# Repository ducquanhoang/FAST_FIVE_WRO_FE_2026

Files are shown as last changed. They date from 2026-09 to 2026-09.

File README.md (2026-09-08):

# FAST-FIVE_WRO_FE_2026
## WRO Future Engineers - Robotics Project Documentation
## Hello! Out team is called "Fast Five"

### Our team
| Photo | Member Name | Role & Experience |
| ----- | --- | --- |
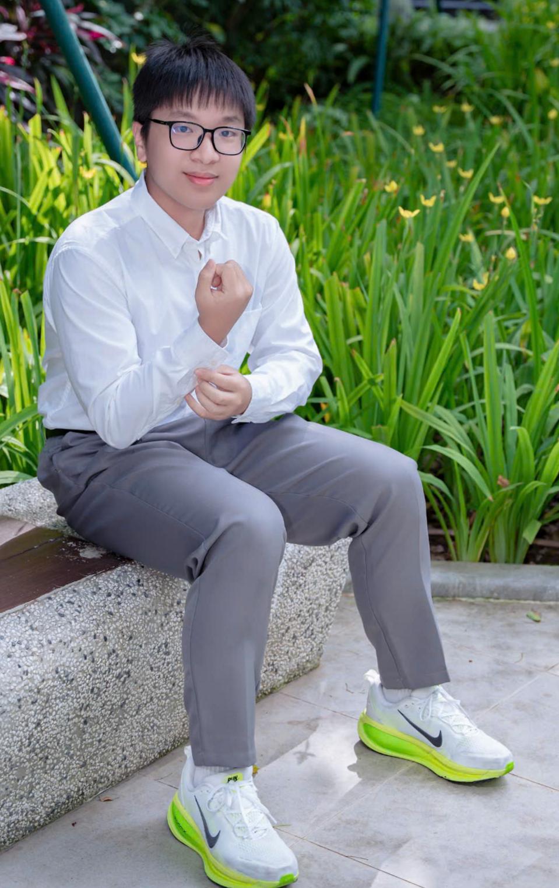
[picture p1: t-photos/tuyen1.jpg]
|| Nguyễn Tự Tuyển | Role: Responsible for documenting the team's development process and photography. Experience: First time competing in an official WRO event |
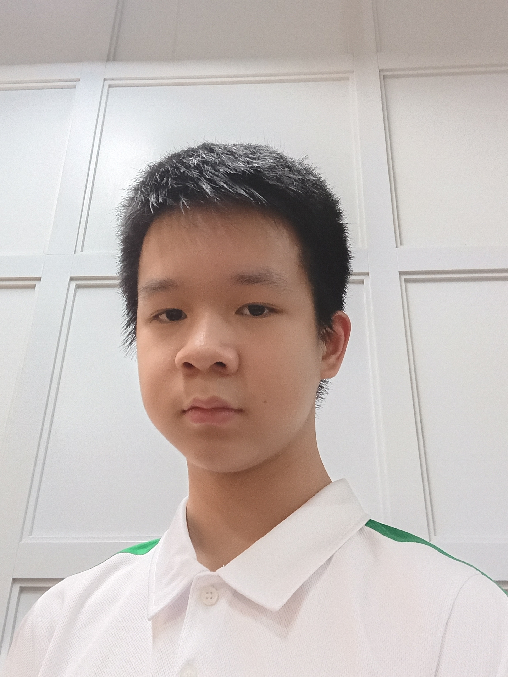
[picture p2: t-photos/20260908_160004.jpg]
|| Hoàng Đức Quân  | Role: Documenting part of the team's development, designing, building and programming the robot. Experience: Previously competed in WRO B2 category 2026 year at hanoi city round, south korean open round, and vietnam national round |

## Table of Contents
- [1. Overview](#1-overview)
  - [1.1 About the Project](#11-about-the-project)
  - [1.2 Robot Images](#12-robot-images)
  - [1.3 Repository Content](#13-repository-content)
- [2. Mobility Management](#2-mobility-management)
  - [2.1 Drive System](#21-drive-system)
  - [2.2 Steering](#22-steering)
  - [2.3 Chassis Design](#23-chassis-design)
- [3. Power and Sense Management](#3-power-and-sense-management)
  - [3.1 Power Source](#31-power-source)
  - [3.2 Sensors and Camera](#32-sensors-and-camera)
  - [3.3 Processing Units](#33-processing-units)
  - [3.4 Port / Wiring Map](#34-port--wiring-map)
  - [3.5 Power Consumption](#35-power-consumption)
- [4. Obstacle Management](#4-obstacle-management)
  - [4.1 Open Challenge](#41-open-challenge)
  - [4.2 Obstacle Challenge](#42-obstacle-challenge)
  - [4.3 Parallel Parking](#43-parallel-parking)
- [5. Source Code](#5-source-code)
  - [5.1 Code Overview](#51-code-overview)
  - [5.2 Code Structure](#52-code-structure)
  - [5.3 Upload / Run Instructions](#53-upload--run-instructions)
- [6. List of Components](#6-list-of-components)
- [7. Building Instructions](#7-building-instructions)
- [8. Future Improvements](#8-future-improvements)
  - [8.1 Software](#81-software-and-reliability)
  - [8.2 Hardware](#82-hardware)

---

## 1. Overview

### 1.1 About the Project

This project of ours is a self‑driving car for the WRO Future Engineers category. The car's a vehicle that can finish the Open Challenge, which asks for three laps on a random track without touching a wall. The car can also complete the Obstacle Challenge, which requires three laps while reading green traffic signs and then doing parallel parking. 

This is the year our team has competed in this category, so much of the project involved learning engineering and programming skills from scratch.

Our robot is built on a custom LEGO Technic + 3D-printed (PLA) chassis, in a rear-wheel differential-drive, Ackermann front-steer configuration, controlled by a LEGO® Education SPIKE™ Prime Hub and a Matrix Robotics M-Vision Cam for onboard image processing. Design priorities, in order, were: a low center of gravity for stability, a lightweight structure to reduce motor strain, and a minimal footprint for maneuverability.

### 1.2 Robot Images

<table>
  <tr>
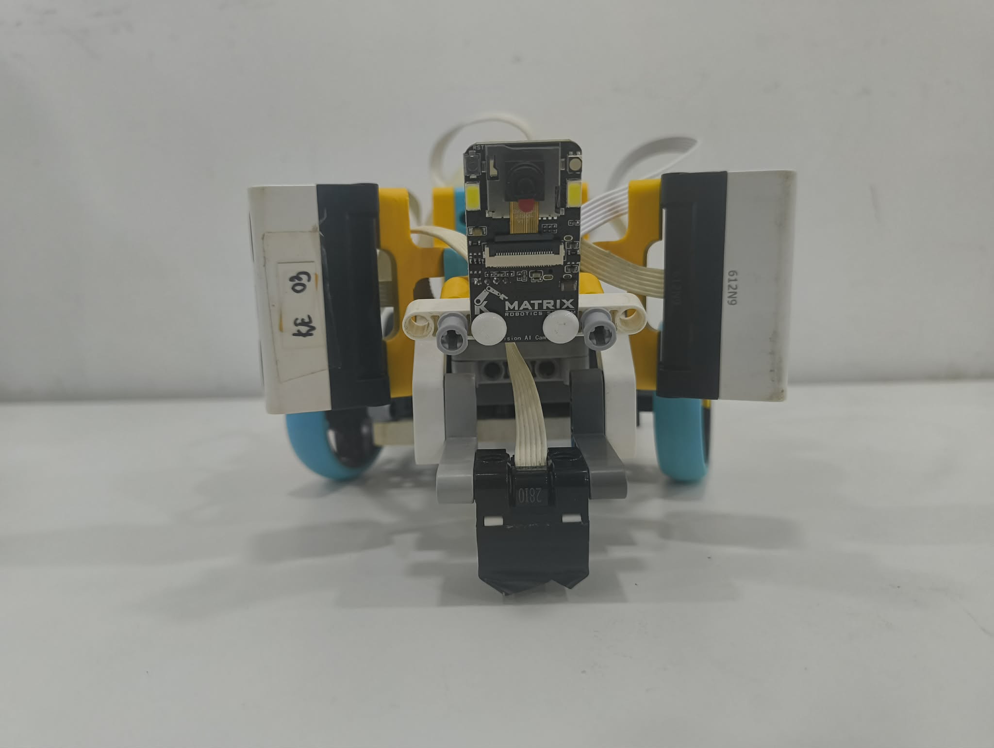
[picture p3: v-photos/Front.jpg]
    <td align="center"><b>Front View</b><br></td>
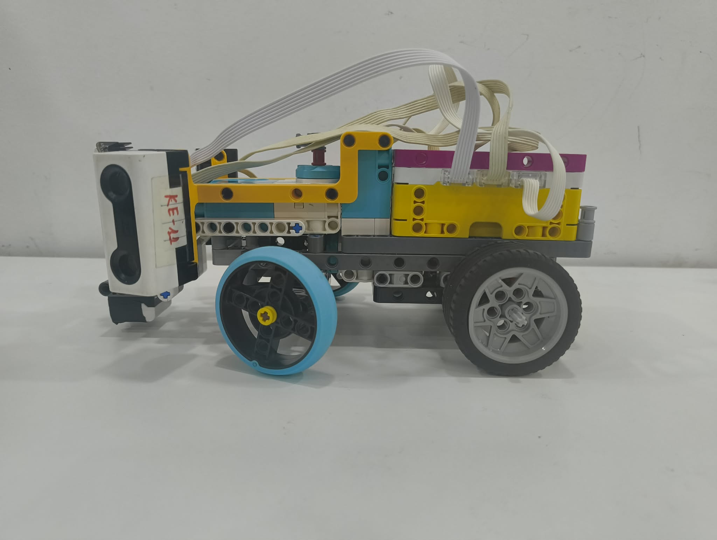
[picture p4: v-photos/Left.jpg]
    <td align="center"><b>Left View</b><br></td>
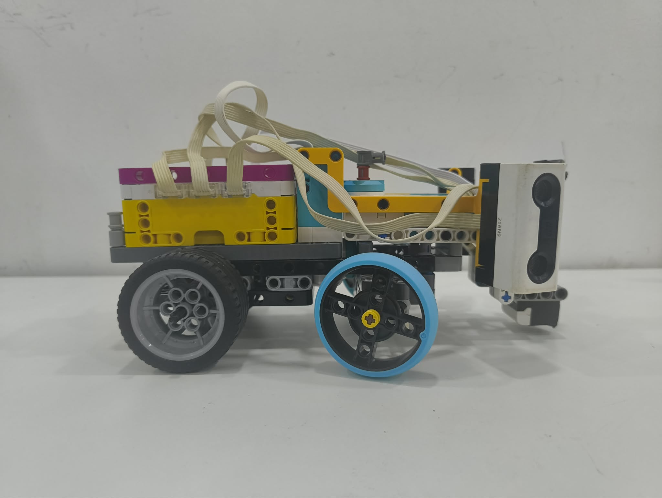
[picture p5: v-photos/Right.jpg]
    <td align="center"><b>Right View</b><br></td>
  </tr>
  <tr>
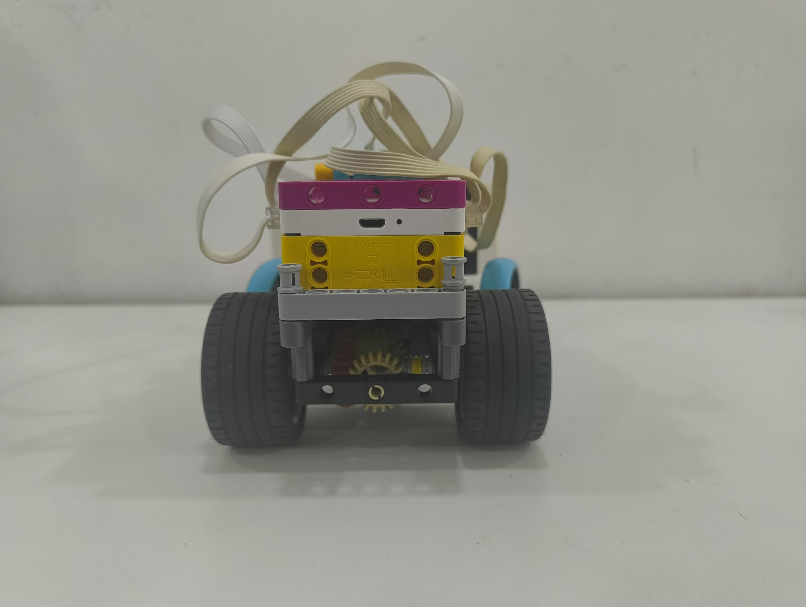
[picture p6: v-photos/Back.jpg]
    <td align="center"><b>Back View</b><br></td>
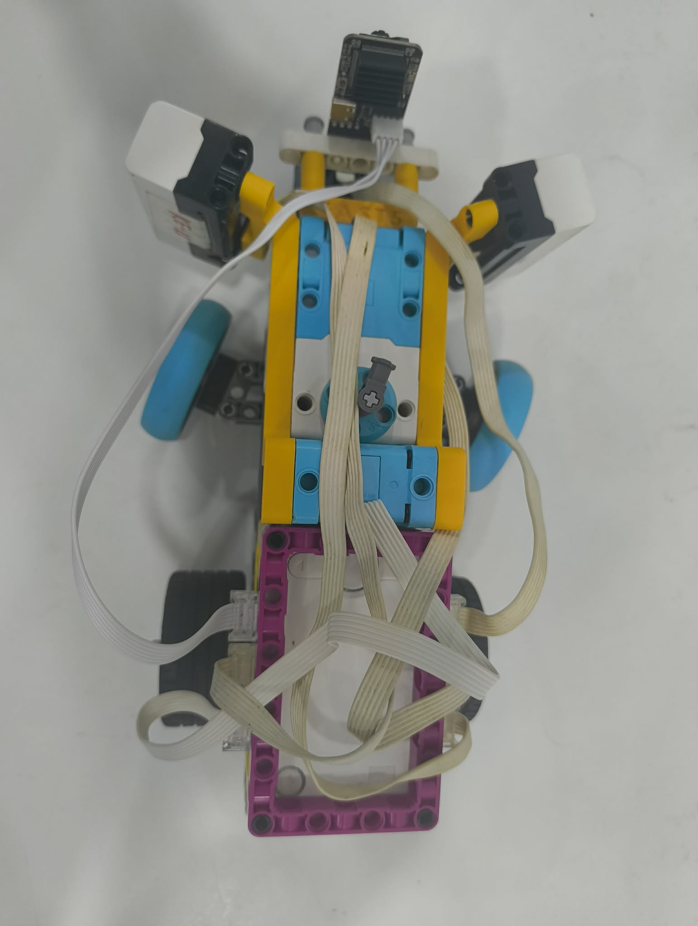
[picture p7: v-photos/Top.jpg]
    <td align="center"><b>Top View</b><br></td>
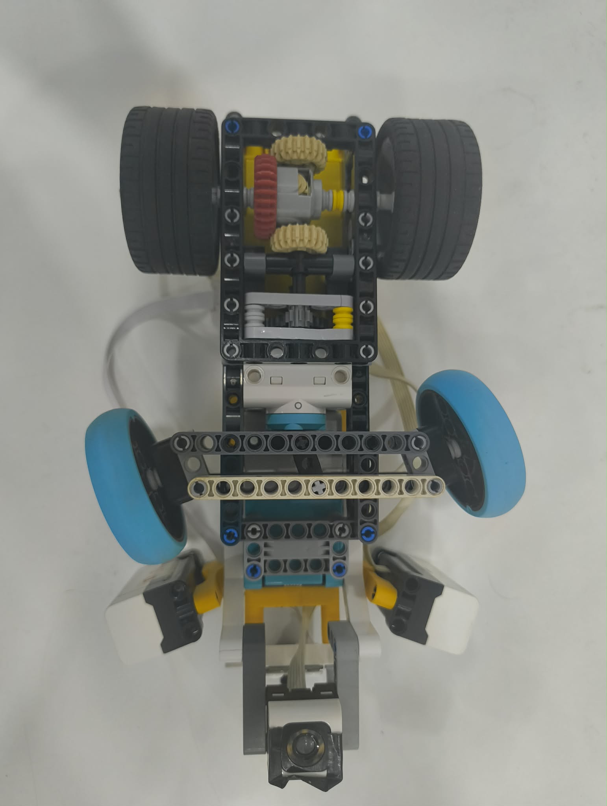
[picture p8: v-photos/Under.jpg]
    <td align="center"><b>Bottom View</b><br></td>
  </tr>
</table>

### 1.3 Repository Content
| Folder | Content |
| --- | --- |
| [t-photos](t-photos) | photo of team members |
| [v-photos](v-photos) | photos of the vehicle, including view from all 6 directions |
| [source code](scr) | python source code for the vehicle's camera and controller |
| [schemes](schemes) | diagrams used |
| [Model](Model) | Photo of component models and 3D model for ultra_adapter and cam_holder |

---

## 2. Mobility management
Design objective: Our chassis is built around 3 goals: stability (keep a low, balanced center of gravity so the robot doesn’t tip or wobble to the side during hard turns or sudden acceleration, and a steady drive base for the camera), efficiency (a lightweight structure so the drive motor isn't fighting excess mass), and maneuverability (a compact footprint that can navigate tight corners and obstacles without sacrificing control).
Motor: LEGO® Technic™ Large Angular Motor (drives the rear differential)
### 2.1 Drive System
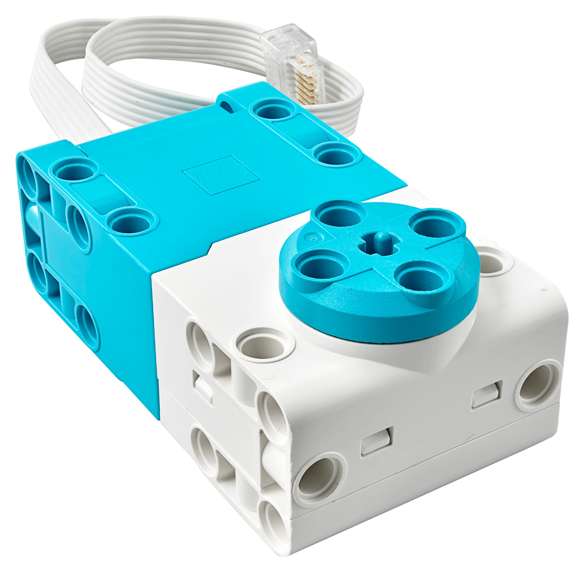
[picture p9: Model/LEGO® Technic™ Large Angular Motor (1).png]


Specifications
* Connector: LEGO® Power Functions 2.0 (LPF2)
* Voltage range: 5–9V (SPIKE Hub nominal: 7.2V)
* No-load speed: ~175 RPM (team measurement, vs ~135 RPM for the stock SPIKE-branded Large Angular Motor)
* Feedback: integrated rotation/position sensor|

Reason for Selection

Higher RPM than the stock SPIKE motor, for faster lap times on the flat competition arena.
Smaller footprint with more mounting-hole positions on the case, giving flexibility in where it sits on the chassis.
Built-in rotation sensor gives closed-loop feedback for encoder-based distance/angle control.

### 2.2 Steering
Motor: LEGO® Technic™ Large Angular Motor + 1:1 gearbox



Specifications
* Connector: LPF2
* Voltage range: 5–9V
* Stall torque: ~40 N·cm with the 1:1 gearbox (team measurement, vs ~25 N·cm for the stock SPIKE Angular Motor)
* Feedback: integrated rotation/position sensor, used for heading/angle-based turns (`MotorB_Angle`)
* Reason for Selection :Highest available stall torque among LEGO Powered Up motors, needed to move the Ackermann linkage under load.
Position feedback lets steering angle be driven and held precisely rather than open-loop.

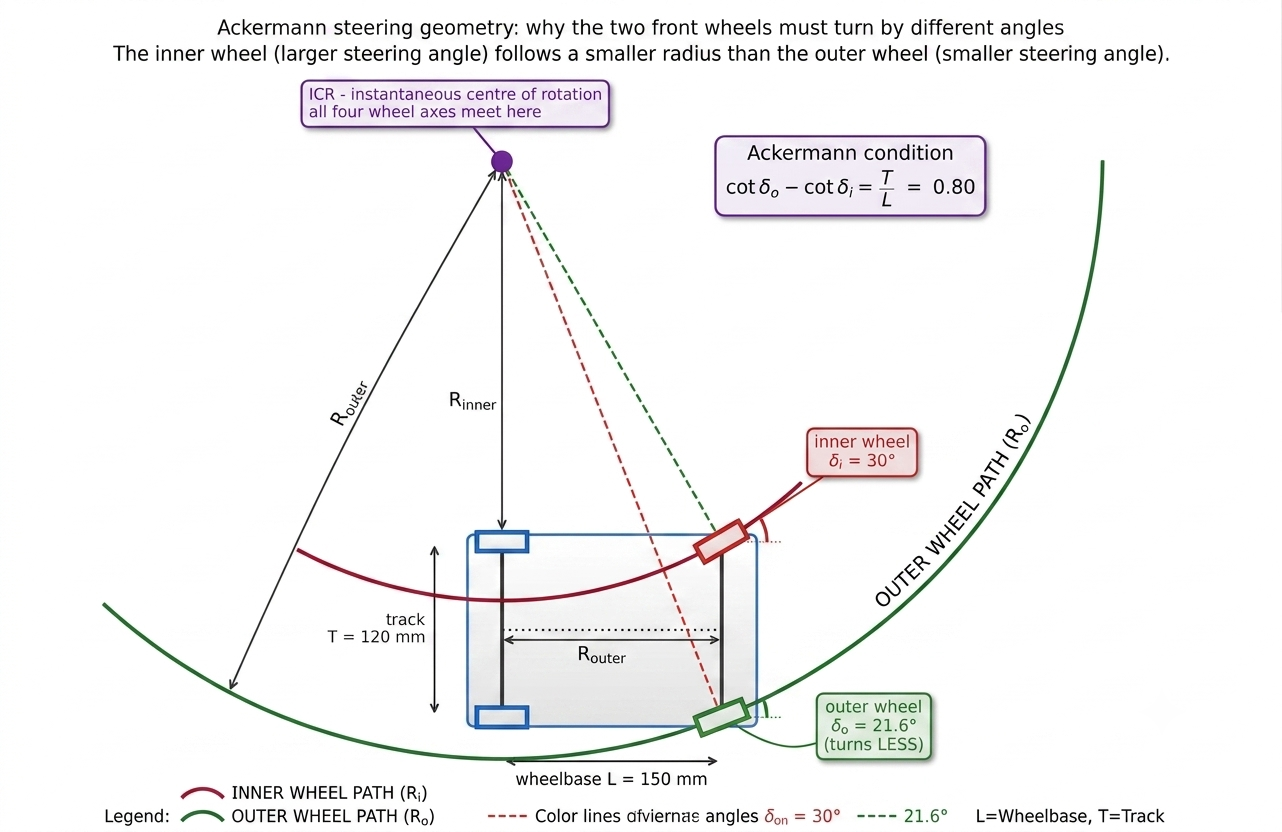
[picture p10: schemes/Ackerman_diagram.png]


Ackermann steering:
When a car turns, the inner and outer front wheels trace circles of different radii, so they need to point at different angles. The inner wheel turns sharper than the outer one. Our steering linkage approximates this relationship so all four wheels roll cleanly with minimal sideways scrubbing, which improves turning accuracy and cuts down on friction losses. 

Why does this happen geometrically?
For a vehicle to corner without any wheel sliding sideways, every wheel has to travel along a circular arc, and all of those arcs must share one common center point: the instantaneous center of rotation (ICR). A wheel only rolls cleanly when its axle points directly at that center. Because our rear axle is fixed, both rear wheels share the same axis line, which pins the ICR somewhere along the extension of that line. The two front wheels then have to angle themselves so their own axle lines also converge on that same point and since the inner front wheel is physically closer to the ICR, it has to turn through a tighter circle, meaning a larger steering angle than the outer wheel. 

The math behind it: for wheelbase L, track width T, and inner/outer steering angles δᵢ and δₒ, the condition that keeps both front axle lines meeting the rear axle line at one point works out to:
cot(δₒ) − cot(δᵢ) = T / L
This relationship isn't linear; the required gap between the two angles grows a lot faster than the angles themselves. At a shallow ~10° steering input the difference between inner and outer angle is only about 1°, but near full lock (~30°) that gap widens to 8° or more. If we'd built a rigid linkage that just kept both wheels parallel, it would look almost correct while driving straight or gently curving, and be badly wrong exactly when precision matters most: sharp corners or a parking maneuver.

Wheels: 49.5 mm SPIKE wheels (front)

Small diameter for agility and quick direction changes at the steered wheels.

Considerations

Even with the 1:1 gearbox, torque at the steering linkage was tighter than expected after the first v2 build - a candidate area to revisit (e.g. a different gear ratio or linkage geometry) if we find the robot under-steering at speed.
### 2.3 Chassis Design

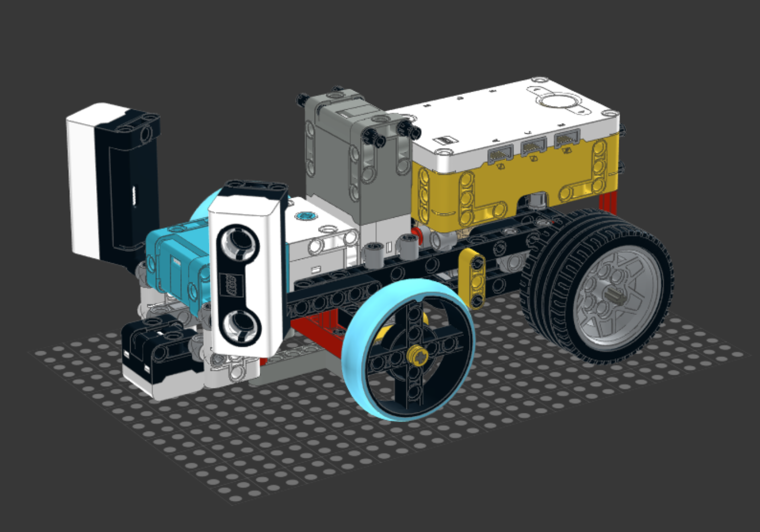
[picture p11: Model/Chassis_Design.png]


Main chassis: LEGO SPIKE Prime Hub, drive and steering motors, ultrasonic sensors, line sensor, structural connectors, and wheel assemblies. 
Rear camera assembly: A structure to hold the Matrix Camera M-Vision AI Cam. 

Why We Put the Camera to the Rear: 
Raising the camera and pushing it toward the rear gives the vision system a much wider field of view, which lets the robot spot the wall and obstacles earlier and more consistently. The trade-off is that a tall mast sitting up high introduces a real risk of tipping the robot, so we had to design the robot so it doesn't tip or wobble to the side during hard turns or sudden acceleration.

Keeping the Elevated Camera From Tipping the Robot: 
To make sure the taller rear mast wouldn't make the robot unstable, we ran a basic static-moment analysis using the rear wheels' contact line with the ground as the pivot point. We compared two moments: 
M₁ - the restoring moment from the main chassis (its mass × its distance from the pivot)
M₂ - the overturning moment from the rear mast/counterweight assembly (its mass × its distance from the pivot)
The robot will stay upright as long as M₁ ≥ M₂, i.e., as long as the main chassis's moment is greater than or equal to the rear assembly's moment. 

Since the main chassis's mass and position are essentially locked in (the hub, motors, and sensors don't move), the only variable we could actually control was the rear assembly. So we minimized both its mass and its distance from the pivot: the camera mount itself, which accounts for most of the rear assembly's weight, sits as close to the pivot as the design allows.

## 3. Power and Sense Management

### 3.1 Power Source

**Battery:** SPIKE Prime rechargeable Li-ion Hub Battery

**Specifications**
- Type: rechargeable lithium-ion, charged in-hub via micro-USB
- Capacity: ~2,000–2,100 mAh (per LEGO Education spare-part listings)
- Working range used in our firmware: 6,900–8,300 mV (see `Battery()` in §5), consistent with a 2-cell Li-ion pack

| Component | Voltage | Current (typical) | Current (peak) | Power (typical) |
|---|---|---|---|---|
| Hub | 7.2 V | 1.0 A | 1.5 A | 7.2 W |
| Camera | 5 V | 0.15 A | 0.3 A | 0.75 W |
| Ultrasonic ×2 | 5 V | 0.04 A | 0.06 A | 0.2 W |
| Drive motors ×2 | 7.2 V | 1.0 A | 2 A | 7.2 W |
| **Total** | | **2.19 A** | **3.86 A** | **15.35 W** |

The battery powers the SPIKE Prime Hub directly; the Hub in turn supplies all motors and sensors over their LPF2 leads, and the M-Vision Cam over its dedicated 5V cable - no separate step-up/step-down conversion is needed anywhere in the system, since the camera's 5V input matches the Hub's output.

Our firmware reads `hub.battery.voltage()`, clamps it to the 6,900–8,300 mV working range, and converts it to a 0–100% estimate so we can catch a low-charge robot before a run.

**Considerations**

Because everything runs off one Hub battery with no separate motor supply, our power architecture is much simpler than a Raspberry Pi-class system (no MOSFET power-switching, no DC-DC boost converter, no separate motor driver IC) - the tradeoff is that we're bound to whatever voltage/current the Hub itself can deliver.
### 3.2 Sensors and Camera
| Sensor | Model | Qty | Purpose |
|---|---|---|---|
| Camera | Matrix Robotics M-Vision Cam (Type-C) | 1 | Lane/sign detection, corner detection |
| Ultrasonic | LEGO SPIKE Prime Ultrasonic Sensor | 2 | Left/right wall distance |
| IMU | Built into SPIKE Prime Hub | 1 | Angular velocity for heading estimation |
| Motor encoders | Built into SPIKE Prime motor | 2 | Distance measurement, steering calibration |
| Color/line sensor | SPIKE Prime color/distance sensor | 1 | Corner line (color) detection |

### Why each sensor was chosen

**Camera: Matrix Robotics M-Vision Cam (Type-C cable pack)**

*Specifications*
- Processor: STM32H7, 480 MHz
- Interface: UART over LPF2 to the SPIKE Prime Hub
- Operating voltage: 5V (matches Hub output directly)
- Color space: LAB (in addition to RGB/HSV)

*Reason for Selection*
- Has its own onboard processor, so the Hub doesn't have to run image-processing algorithms itself — this saves battery and keeps the Hub's CPU free for motor/sensor control.
- Supports LAB color space, which separates brightness (L) from color (A/B). Since the A/B axes stay comparatively stable when the arena's lighting shifts brighter or darker, LAB gives more consistent line/color detection than RGB or HSV under variable lighting.

*Tasks:* line following and wall-fill detection (Open Challenge); red/green traffic-sign blob detection, magenta parking-wall detection, and lap-boundary color detection (Obstacle Challenge).

**Distance sensing: 2× LEGO® Technic™ Distance Sensor (ultrasonic)**

*Specifications (manufacturer)*
- Sensing technology: ultrasonic
- Range: 50–2,000 mm (fast-sensing mode: 50–300 mm)
- Accuracy: ±1 cm
- Extras: 4-segment programmable LED "eyes"; detachable LPF2 breakout on the rear

*Tasks:* one sensor on each side reads distance to the left/right walls. At the start of a run, this tells the robot whether the course is Clockwise or Counterclockwise (by checking which side has a wall); during a run, it feeds `Ultra_err()`/`Ultra_steer()` to hold a consistent stand-off from the wall and correct heading error.

**Ground sensing: LEGO® Technic™ Color Sensor**

*Specifications (manufacturer)*
- Detects 8 discrete colors, plus RGB/HSV values
- Measures reflected light intensity (for line-following) and ambient light
- High sample rate for consistent, repeatable readings

*Tasks:* reads ground color for lap-boundary/start-line detection, feeding `Color_read()` and `Color_line_count()` for lap counting.

## 3.3 Processing Units

**Controller:** LEGO® Education SPIKE™ Prime Hub

| | Mindstorms EV3 | SPIKE Prime |
|---|---|---|
| CPU Clock Speed | 300 MHz | 100 MHz |
| Weight (incl. battery) | 385 g | ~200 g |
| Volume | 0.388 L | 0.158 L |

**Reason for Selection**

We chose SPIKE Prime over EV3 even though its CPU clock speed is lower, because it's roughly half the weight and less than half the volume of the EV3 Hub — both of which matter more for our low-CG, lightweight design goals than raw clock speed, given that the M-Vision Cam (not the Hub) does the heavy image-processing work.

## 3.4 Port / Wiring Map

Everything connects to the Hub over standard LEGO LPF2 cables — no custom wiring harness or PCB is needed. Current assignments (from `FE_Functions.py`):

| Hub Port | Device | Role |
|---|---|---|
| A | Matrix M-Vision Cam | Line / wall / traffic-sign detection |
| B | Technic Large Motor | Drive (rear differential) |
| C | Technic XL Motor | Steering (Ackermann linkage) |
| D | Distance Sensor (right) | Right-wall distance |
| E | Color Sensor | Ground color / lap detection |
| F | Distance Sensor (left) | Left-wall distance |

## 3.5 Power Consumption

All components are powered from the SPIKE Prime Hub's own 7.3 V Li-Ion battery.

| Component | Voltage | Current (typical) | Current (peak) | Power (typical) |
|---|---|---|---|---|
| SPIKE Prime Hub | 7.2 V | 1.0 A | 1.5 A | 7.2 W |
| M-Vision Camera | 5 V (Type-C) | 0.15 A | 0.3 A | 0.75 W |
| Ultrasonic ×2 | 5 V (from hub) | 0.04 A | 0.06 A | 0.2 W |
| Drive motors ×2 | 7.2 V | 1.0 A | 2.0 A | 7.2 W |
| **Total** | | **2.19 A** | **3.86 A** | **15.35 W** |

---

## 4. Obstacle Management

The competition has two runs:
- **Open Challenge:** three laps around a randomly-sized field, in a randomly-chosen direction, without touching a wall.
- **Obstacle Challenge:** three laps while reading traffic signs - pass a red sign on its right, a green sign on its left - then parallel-park in a marked bay.

We split our strategy into the same three phases:

### 4.1 Open Challenge

Two boxes are drawn on the left and right of the camera frame. Pixels within a tuned RGB threshold count as "black," and the robot centers itself on the track by comparing the black-fill ratio of the two boxes, correcting with **PID** steering. A box at the center of the frame watches for the orange/blue start-line color; whichever color it sees first tells the robot whether the course is Clockwise or Counterclockwise. Two small boxes at the bottom of the frame catch the case where the robot gets close enough to a wall that the main boxes lose the line, switching to a "priority correction" mode driven by those bottom boxes instead - this stops the robot from hugging the wall or losing track when the front sensors go unreliable. A tunable default wall-hugging offset (e.g. +30°) keeps the robot tracking tightly and minimizes lap time.

<details>
<summary><b>Click here to show Open Challenge code excerpt</b></summary>

```python
Add = 200 if Cam_val[0]>10 and Cam_val[1]>10 else 0
while GetColor() == 0:
    steering(0)
Drive.reset_angle(0)
while abs(Drive.angle()) < Add:
    steering(0)

if GetColor() == 1:
    ColorCondition = 1
    Plus = -30
else:
    ColorCondition = -1
    Plus = 40

for i in range(11):
    while GetColor() != ColorCondition:
        SteerCamOpen(ColorCondition, Plus)
    while GetColor() == ColorCondition:
        SteerCamOpen(ColorCondition, Plus)
Drive.reset_angle(0)
while abs(Drive.angle()) < 2000:
    SteerCamOpen(ColorCondition, Plus)
```

</details>

### 4.2 Obstacle Challenge

Sign avoidance runs as a four-state routine on the Hub, layered on the same wall-following and corner-counting loop as the Open Challenge (`Ultra_err()` for wall stand-off, `Steer_err()` for the corner-count-based turn target). Each cycle the camera reports an x/y position and color for the nearest sign, plus the percentage of black track surface in view; the state machine below decides what to do with that reading.

**Scanning:** with no sign in view, the robot drives the same baseline heading as the Open Challenge, just with a wider 90° corner cut (`Steer_err(90)` vs. `Steer_err(75)`) to leave more room to spot and clear signs. The moment a sign appears, it switches to tracking it.

**Approaching:** the robot steers straight at the sign using its camera x-offset from center, holding the last good heading if the camera briefly loses it. Once the sign fills enough of the frame (`y >= 100`), the robot commits to the avoidance swing.

**Avoiding:** the target heading swings about 60° off the approach line, the side set by the sign's color, matching the red-right / green-left rule, clamped to within 85° of the current baseline heading so it can't over-rotate. It holds that swing until the track surface reappears (`black` fill above 60%), or gives up and returns to Scanning if 250 encoder-degrees pass without finding it.

**Settling:** for a short window after clearing a sign, until `black` fill passes 70% or 200 more encoder-degrees pass, the robot ignores new sign readings, so it doesn't immediately re-trigger on the one it just passed.

Drive power is also capped lower than the Open Challenge (30–50% vs. 70–100%), and steering runs through `SteerObs()`, a gentler, ±40°-clamped controller — instead of `Steer()`, trading speed for the precision needed to line up on each sign.

*(This section previously described a per-frame PD/blob-width design; it's been rewritten to match the state-machine approach now in `main_obstacle()`.)*

### 4.3 Parallel Parking

After completing 3 laps, the robot aligns to the wall using the same wall-following method as above, then drives until the magenta parking-lot color crosses a specific X-coordinate in the camera frame. From that trigger point, a **pre-programmed, encoder-based maneuver sequence** completes the park - deliberately not a fully vision-guided park, since the travel distance involved is short enough that encoder error stays within an acceptable margin, and it avoids depending on vision precision we haven't yet fully validated for this sub-task.

<p align="right"><a href="#top">Back To Top</a></p>

---

## 5. Source Code

All the code used in the robot can be found [here](scr)

### 5.1 Code Overview

- **Language/runtime:** Pybricks (MicroPython) on the SPIKE Prime Hub.
- **Vision:** OpenMV IDE on the M-Vision Cam, using the `LPF2` import so it can talk to the Hub.
- **Custom libraries:** `MXLineT_Lib` (camera/line-tracker interface).

### 5.2 Code Structure

```txt
repo-root
└─ src
   ├─ Camera
   │  ├─ LPF2.py            # External library (depends on libcamera)
   │  ├─ main.py
   ├─ Controller       
   │  ├─ FE_Functions.py 
   │  ├─ FE_Portview.py               
   │  ├─ FE_RUN.py          # Executable for both open and obstacle challenges         
```

**Key function groups in `FE_Functions.py`:**

| Group | Functions | Role |
|---|---|---|
| Utility | `NumberLimit_Clamp()`, `Enc_cal()`, `dist_cal()` | Clamp a value to a safe range; convert cm → motor degrees and back |
| Power | `Battery()` | Reads Hub voltage, clamps 6,900–8,300 mV, returns battery % |
| Color / laps | `Color_read()`, `Color_line_count()` | Classify raw RGB as a line color; count line crossings for laps |
| Wall following | `Ultra_err()` | Compute a steering correction from the two ultrasonic distance sensors |
| Corner targeting | `Steer_err()` | Turn the line-crossing count into a target turn angle (90° every two crossings, plus a tunable per-corner cut) |
| Heading reference | `Theta()`, `Compass()`, `ReTheta()` | Gyro (IMU)-based heading: signed heading, raw 0–360° compass, and signed error to a target heading |
| Drive/steer profiles | `MotorB_On/Stop/Time/Degs/degree/smooth/3step/dist/...`, `MotorB_Angle` | Inherited motor-profile helpers (accel/decel smoothing, 3-stage speed profiles, gyro turn-to-angle), built around a separate `motorB`/`motorC` pair rather than the `move`/`steer` objects the run loops below actually drive — not called by either challenge's main loop in `FE_RUN.py` |

> **Fixed:** the old `Ultra_steer()` syntax gap (`90*Line_count // 2 Line_count % 2 * 45 ...`, missing an operator between `//2` and `Line_count`) is resolved in the current code. The function is now `Steer_err(corner)`, reading `90*(Line_count // 2) + (Line_count % 2) * corner` ,correctly parenthesized, with `corner` passed in per call (`75` for the Open Challenge, `90` for the Obstacle Challenge) instead of a hard-coded `45`.

**Key functions in `FE_RUN.py`:**

| Function | Role |
|---|---|
| `Steer(angle)` | Steering controller (proportional + accumulated error) used in the Open Challenge |
| `SteerObs(angle)` | Gentler, ±40°-clamped steering controller used in the Obstacle Challenge (see 4.2) |
| `portview()` | Bench-test loop — prints battery, encoder, gyro, distance-sensor, color, and camera readings every 500 ms |
| `main_open()` | Open Challenge entry point |
| `main_obstacle()` | Obstacle Challenge entry point (see 4.2) |

### 5.3 Upload / Run Instructions

1. Install the [Pybricks firmware](https://code.pybricks.com) onto the SPIKE Prime Hub (one-time step, via the Pybricks web IDE over USB or Bluetooth).
2. Connect to the Hub from the Pybricks IDE (or VS Code with the Pybricks extension) and open `FE_Functions.py` plus the relevant challenge script.
3. Flash/run the program on the Hub.
4. Separately, open the corresponding vision script in **OpenMV IDE**, connect to the M-Vision Cam over its Type-C cable, and run/save it to the camera so it starts automatically on power-up.
5. Power on the robot - Hub and camera boot together once battery power is applied.

<p align="right"><a href="#top">Back To Top</a></p>

---

## 6. List of Components

| Component | Quantity | Source / Reference |
|---|---|---|
| LEGO® Education SPIKE™ Prime Hub | 1 | LEGO Education |
| SPIKE Prime rechargeable Hub battery | 1 | [LEGO Education 45610](https://education.lego.com/en-us/products/lego-technic-large-hub-battery/45610/) |
| Technic™ Powered Up Large Motor (drive + steering) | 2 | [LEGO 88013](https://education.lego.com/en-us/products/lego-technic-large-angular-motor/45602/) |
| LEGO differential gear | 1 | LEGO Technic |
| 62.3 mm Technic tires (rear) | 2 | LEGO Technic |
| 49.5 mm SPIKE wheels (front) | 2 | LEGO SPIKE Prime |
| Matrix Robotics M-Vision Cam + Type-C cable pack | 1 | Matrix Robotics |
| LEGO® Technic™ Distance Sensor (ultrasonic) | 2 | [LEGO Education 45604](https://education.lego.com/en-us/products/lego-technic-distance-sensor/45604/) |
| LEGO® Technic™ Color Sensor | 1 | [LEGO Education 45605](https://education.lego.com/en-us/products/lego-technic-color-sensor/45605/) |
| Custom 3D-printed PLA parts (mounts, brackets) | Various | 3D-printed in-house |
| LEGO Technic structural elements | Various | LEGO Technic |

**Printers Used:**

- [Bambu Lab P1S](https://asia.store.bambulab.com/products/p1s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)

<p align="right"><a href="#top">Back To Top</a></p>

---

## 7. Building Instructions

All the code used in the robot can be found [here](scr)

Step 0 - Print the 3D parts: print all custom PLA parts listed in §7.

Step 1 - Assemble the steering system: front wheel linkages → Ackermann/reverse-Ackermann linkage → mount to chassis → attach XL steering motor → secure front wheels.Using File of the Chassis can be found here

Step 2 - Assemble the drivetrain: rear wheel axles → differential → Large drive motor → secure to chassis → attach rear wheels.

Step 3 - Mount electronics: SPIKE Prime Hub placement → M-Vision Cam mounting/aiming → Distance Sensors (left/right) → Color Sensor → route and connect all LPF2 cables per the port map in §3.4.

Step 4 - Upload the software: follow §5.3 to flash the Hub and camera, then power on and test.

<p align="right"><a href="#top">Back To Top</a></p>

---

## 8. Future Improvements

### 8.1 Software and reliability

- Dual-controller architecture (Raspberry Pi for vision + Arduino for real-time motor control) for parallel processing and deterministic timing.
- Lightweight neural-network vision to replace hand-tuned color thresholds.
- External 9-axis IMU for better drift correction.
- Robust UART communication: packet retransmission, timestamps, command validation.
- Expanded watchdogs (ultrasonic/IMU/encoder staleness + auto re-calibration) and crash detection/recovery via accelerometer spikes.
- Automatic retry logic for sensor failures/timeouts.
- Profiling and optimizing critical loops; centralized tunable-parameter config file.
- Structured, real-time logging; backup wall-following/waypoint navigation modes.

### 8.2 Hardware

- Rigid custom 3D-printed chassis to reduce flex and improve steering precision.
- Higher-torque motors for more consistent parking.

<p align="right"><a href="#top">Back To Top</a></p>

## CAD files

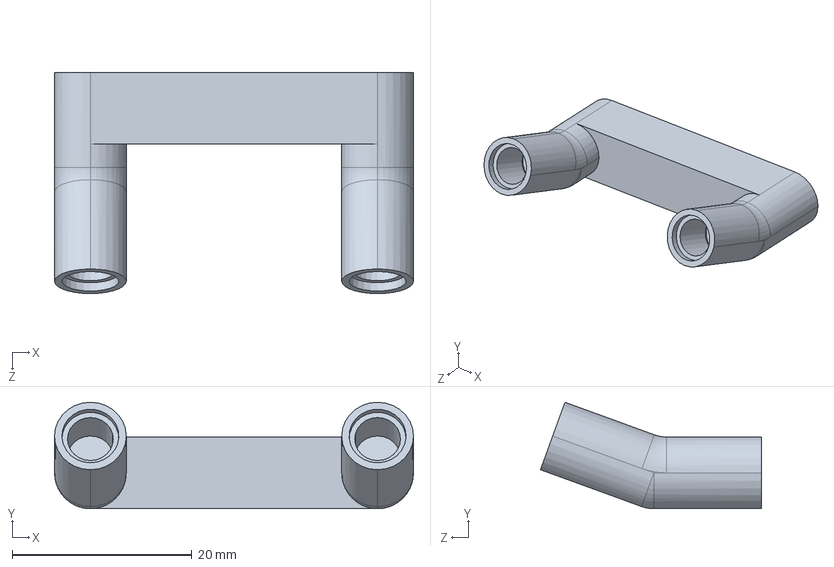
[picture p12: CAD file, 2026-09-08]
Model/cam_holder.SLDPRT
40.0 x 11.9 x 24.6 mm

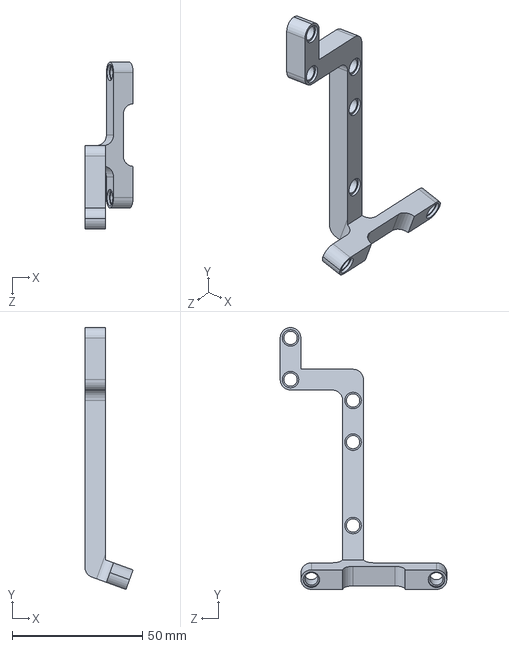
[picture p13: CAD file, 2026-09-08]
Model/Ultra_adapter.SLDPRT
18.5 x 100.5 x 64.0 mm

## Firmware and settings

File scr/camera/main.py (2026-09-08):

import sensor, image, time
import gc, utime
import micropython
import LPF2
from machine import Pin
from pyb import LED
micropython.alloc_emergency_exception_buf(200)

# ---------------- Color thresholds ----------------
# Format: (L_min, L_max, A_min, A_max, B_min, B_max)
# Index 0 -> RED, Index 1 -> GREEN.  This list order defines the colour ID:
#   colour 0 = red, colour 1 = green
red_threshold   = (14, 52, 45, 80, 10, 60)   # red block
red_threshold_l = (5,40,5,60,0,45) # red block darkened
red_threshold_r = (5,40,10,60,0,45) # red block darkened
green_threshold = (17, 70, -50,  -19,  6, 36)   # green block
black_threshold = (0, 35, -15, 15, -10, 20)
white_threshold = (55, 85, -10, 20, -15, 15)
pink_threshold = (25, 40, 45, 60, 5, 35)
thresholds = [red_threshold, green_threshold, red_threshold_l,  red_threshold_r]
#(0,0,0,0,0,0)
#Define the middle ROI
mid_roi = (130, 50, 60, 40)
mid_roi3 = (70, 90, 180, 60)
mid_roi2 = (70, 150, 180, 50)
white_roi = (70, 100, 180, 100)

mid = (60, 150, 200, 60)

# ---------------- Caamera setup ----------------
sensor.reset()
sensor.set_vflip(True)
sensor.set_hmirror(True)
sensor.set_pixformat(sensor.RGB565)       # Format: RGB565
sensor.set_framesize(sensor.QVGA)         # Size: QVGA (320 x 240)
sensor.set_auto_gain(True)               # MUST be OFF for stable colour tracking
sensor.set_auto_whitebal(True)           # MUST be OFF for stable colour tracking
clock = time.clock()                      # Clock object to track the FPS

# ---------------- LUMP / LPF2 setup ----------------
# We send 4 x Int16 values: [X, Y, colour, count]  -> 8 bytes (a clean power of 2)
#   X      : centre x of the chosen block (0..320), 0 if none
#   Y      : centre y of the chosen block (0..240), 0 if none
#   colour : 0 = red, 1 = green, -1 = no block detected
#   count  : total number of red+green blocks seen this frame
modes = [LPF2.mode('OpenMV-ALL', size=8, type=LPF2.DATA16, format='3.0'),]
DataToSend = [0, 0, 0, 0, 0, 0, 0, 0]                # X, Y, colour, count
lpf2 = LPF2.Prime_LPF2(3, 'P4', 'P5', modes, 62, timer=4, freq=10)
lpf2.initialize()

# ---------------- Main loop ----------------
while True:
    # If the LEGO brick is not connected, re-initialise
    if not lpf2.connected:
        LED(1).off()
        LED(2).off()
        LED(3).on()
        lpf2.sendTimer.deinit()
        utime.sleep_ms(50)
        lpf2.initialize()
    else:

        clock.tick()
        img = sensor.snapshot()
        # Black out the top strip (beyond the game field) so its background
        # noise can never form a blob. Must be done BEFORE find_blobs().
        img.draw_rectangle((0, 0, 320, 50), color=(0, 0, 0), fill=True)
        # img.draw_rectangle(60, 200, 200, 40, color=(0, 0, 0), fill=True)
        blobs = img.find_blobs(thresholds, area_threshold=300, pixels_threshold=600)



        # --- MID ROI ---
        mid_blobs = img.find_blobs([black_threshold], roi=mid_roi, pixels_threshold=5, area_threshold=5, merge=True)
        mid_black_pixels = sum([b.pixels for b in mid_blobs])
        mid_total_pixels =  mid_roi[2] *  mid_roi[3]
        mid_black_percent = ( mid_black_pixels /  mid_total_pixels) * 100 #180


        # --- MID ROI2 ---
        mid_blobs2 = img.find_blobs([black_threshold], roi=mid_roi2, pixels_threshold=5, area_threshold=5, merge=True)
        mid_black_pixels2 = sum([b.pixels for b in mid_blobs2])
        mid_total_pixels2 =  mid_roi2[2] *  mid_roi2[3]
        mid_black_percent2 = ( mid_black_pixels2 /  mid_total_pixels2) * 100 #120

        # --- MID ROI3 ---
        mid_blobs3 = img.find_blobs([black_threshold], roi=mid_roi3, pixels_threshold=5, area_threshold=5, merge=True)
        mid_black_pixels3 = sum([b.pixels for b in mid_blobs3])
        mid_total_pixels3 =  mid_roi3[2] *  mid_roi3[3]
        mid_black_percent3 = ( mid_black_pixels3 /  mid_total_pixels3) * 100

        # # Draw the MID ROI box on the IDE preview (blue outline)
        img.draw_rectangle(mid_roi, color=(0, 0, 255))
        img.draw_rectangle(mid_roi2, color=(0, 0, 255))
        img.draw_rectangle(mid_roi3, color=(0, 0, 255))

        max_size    = 0
        block_x     = 0
        block_y     = 0
        block_color = -1      # -1 = nothing found
        count       = 0

        for b in blobs:
            if b.code & 1 or b.code & 4 or b.code & 8:
                color = 0                # red
                draw_col = (255, 0, 0)
            elif b.code & 2:
                color = 1                 # green
                draw_col = (0, 255, 0)
            else:

                continue

            # Density (extent) = blob pixels / bounding-box area. A solid block
            # sits near 1.0; ragged background noise is much lower. Only blobs
            # that fill at least 80% of their bounding box qualify.
            if b.code & 1:
                print("red1")
                print (b.density)
            elif b.code & 4:
                print("red2")
                print (b.density)
            elif b.code & 8:
                print("red3")
                print (b.density)
            elif b.code & 2:
                print("green")
                print (b.density)

            if b.density < 0.63  and b.code & 1:
                continue
            if b.density < 0.63 and b.code & 2:
                continue
            if b.density < 0.55 and (b.code & 4 or b.code & 8):
                continue
            if b.area < 600:
                continue
            if b.w/b.h > 0.95:
                continue
            if (mid_black_percent3 > 60) and b.y < 80:
                continue
            if mid_black_percent2 >= 50 and b.y < 90:
                continue
            if mid_black_percent3 >= 80 and b.y < 150:
                continue

            # Debug drawing on the IDE preview
            img.draw_rectangle(b.rect, color=draw_col)
            # img.draw_cross(b.cx(), b.cy(), color=draw_col)
            count += 1

            # Keep the largest blob = the closest / most relevant block
            if b.cy > block_y:
                max_size    = b.area
                block_x     = b.cx
                block_y     = b.cy
                block_color = color

            if block_color == -1:
                LED(1).off()
                LED(2).off()
                LED(3).off()
            elif block_color == 0:
                LED(1).on()
                LED(2).off()
                LED(3).off()
            else:
                LED(1).off()
                LED(2).on()
                LED(3).off()
            LED(1).off()
            LED(2).off()
            LED(3).off()


        mid_black_percent = max(mid_black_percent, mid_black_percent2) if count == 0 else mid_black_percent2
        img.draw_string((1, 1), "X:%d Y:%d Color:%d Count:%d Black:%d FPS:%d" %
                (block_x, block_y, block_color, count, mid_black_percent, int(clock.fps())))



        DataToSend = [block_x, block_y, block_color, int(mid_black_percent)]

        # print (block_x, block_y, block_color, count, max_size)
        # Send the data to the Spike Prime hub
        if lpf2.current_mode == 0:
            lpf2.load_payload('Int16', DataToSend)

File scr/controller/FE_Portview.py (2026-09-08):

from FE_Functions import*
print("\x1b[H\x1b[2J",end="")
motorB.reset_angle(0)
motorC.reset_angle(0)
Time_End = StopWatch()
print("\x1b[H\x1b[2J",end="")
while True: 

    print("Battery:",str(hub.battery.voltage()/1000)[0:3],"/8.0 (V)", str(hub.battery.voltage()/10 / 8), "%")
    print("--gyro--")
    heading = hub.imu.heading()
    print("gyro:",heading,"degs")
    print("Compass:", Compass())
    print("Theta:",Theta())
    print("ThetaXY:", ReTheta(0))

    print("--CAM--")
    val = Camera.read(0) #purple_x, purple_y , orange_x, orange_y
    print(val)
    print("*purple*/ x:", val[0], "y:",val[1]//10, "quantity:",val[1]%10)
    print("*orange*/ x:", val[2], "y:",val[3]//10, "quantity:",val[3]%10)

    print("--Sensor--")
    print("Ultra_left/Ultra_right:", sL.distance(),"/", sR.distance())
    print("ultra raw:", sLraw.read(0), "/", sRraw.read(0))
    print("colorsensor raw:", s1raw.read(5))

    print("--motor--")
    print("Move_EncB:",motorB.angle(),"Steer_EncC:",motorC.angle())

    if (Button.CENTER in hub.buttons.pressed()):
        hub.speaker.beep(698, 200)
        motorB.reset_angle(0)
        motorC.reset_angle(0)
        wait(1000)
    wait(1000)
    print("\x1b[H\x1b[2J",end="")

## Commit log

2026-09-08 Rename LEGO® Technic™ Large Angular Motor (1).png to Model/LEGO® Technic™ Large Angular Motor (1).png
2026-09-08 Controller & Camera python files
2026-09-08 Uploaded source code for camera & controller
